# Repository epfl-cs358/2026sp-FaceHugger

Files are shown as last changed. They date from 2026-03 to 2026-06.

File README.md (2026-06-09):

# FaceHugger: An Open-Source Quadruped Robot that Walks, Dances, and Flips

main-robot-stance

In this repo you will find the CAD, firmware, app, simulation, and animation tooling for the FaceHugger quadruped.
This robot was designed and built from scratch by a team of 6 students at EPFL in the [Making Intelligent Things course (CS-358)](https://edu.epfl.ch/coursebook/en/making-intelligent-things-b-CS-358-B) during the Spring 2026 semester.

Find out how to build it and how it works in the _[FaceHugger Wiki](https://epfl-cs358.github.io/2026sp-FaceHugger/)_.

## See it in action

https://github.com/user-attachments/assets/f48a0bcb-4729-4eee-8e89-9a81a8c70e2d

*General moves: walk and wave clips*

https://github.com/user-attachments/assets/28df8788-2bca-48f2-9b82-b47c927adb80

*Dancing clip*

https://github.com/user-attachments/assets/d9c9cdf4-f84c-4cda-ada7-795cacb76790

*Auto-flip: the robot detects when it's upside-down and mirrors its pose*

## Documentation

Project docs are a MkDocs Material wiki under [`wiki/`](wiki/).

- **Live site:** _[FaceHugger Wiki](https://epfl-cs358.github.io/2026sp-FaceHugger/)_
- **How to contribute / fill it out:** see [`wiki/README.md`](wiki/README.md) - structure, local preview,
  adding images/video/3D models/notebooks, and the per-member assignments.

## Repo layout

- `cad/` - Fusion 360 design files and export add-ins
- `code/simulation/` - URDF generator + PyBullet sim ([README](code/simulation/README.md))
- `code/firmware/` - ESP32 firmware (PlatformIO)
- `code/remote-control-app/` - Expo / React Native control app
- `animation/` - Blender rig and animation tooling
- `wiki/` - project documentation (published to GitHub Pages)

## Getting started

```bash
# Simulation
cd code/simulation && conda env create -f environment.yml && conda activate facehugger
python code/facehugger.py sim

# Wiki (local preview)
python -m venv .venv-docs && source .venv-docs/bin/activate && pip install -r requirements-docs.txt
mkdocs serve

# Remote-control app
cd code/remote-control-app/MyApp && npm install && npx expo start --web

# Firmware
cd code/firmware && pio run -t upload
```

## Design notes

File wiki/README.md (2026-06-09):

# Working on the FaceHugger wiki

This folder is the source of the project wiki (a [MkDocs Material](https://squidfunk.github.io/mkdocs-material/)
site). This page explains how the wiki is built and how to contribute to it. It is **not** published to the
site itself; it's here for editors.

## How the wiki works

- **Source:** every page is a Markdown file under `wiki/`. The config is `mkdocs.yml` at the repo root.
- **Two pillars:** `wiki/guide/` is the build guide (for builders/newcomers); `wiki/reference/` is the
  technical depth. Each is a top tab on the site.
- **Navigation** comes from a `.pages` file in each folder (it sets the section's title and page order).
  There is no hand-maintained nav list. Add a page by creating the `.md` and adding its filename to that
  folder's `.pages`.
- **`_context/` folders** hold the original project docs copied verbatim, as source material for writing the
  real pages. They are excluded from the built site but stay in the repo so you can read them on GitHub.
  **Read the `CONSISTENCY-CHECK` note at the top of each `_context/` file first** - many describe designs
  that changed or were never built. Adapt the content, don't paste it. Don't edit `_context/` files; they get
  deleted once the corresponding page is written.
- **Publishing:** a push to `main` touching `wiki/**` runs `.github/workflows/deploy-docs.yml`, which builds
  with `mkdocs build --strict` and deploys to GitHub Pages. A broken link fails the build.

## Working on this branch

We write the wiki on the **`feat/wiki-setup`** branch. The live site only updates when this is merged to
`main`, so until then, **preview locally**.

```bash
git clone https://github.com/epfl-cs358/2026sp-FaceHugger.git
cd 2026sp-FaceHugger
git checkout feat/wiki-setup

# one-time: docs toolchain in an isolated venv
python -m venv .venv-docs
source .venv-docs/bin/activate
# for Windows : .venv-docs/Scripts/activate
pip install -r requirements-docs.txt

# live preview at http://127.0.0.1:8000 (rebuilds as you save)
source .venv-docs/bin/activate && mkdocs serve
# for Windows : .venv-docs/Scripts/activate ; mkdocs serve
```

Edit your pages, then:

```bash
git add wiki/...
git commit -m "docs(wiki): write <page>"
git push                       # pushes to feat/wiki-setup
```

Pull often (`git pull`) so you stay in sync with teammates on the same branch.

## Writing a page

- Pages are stubs with `!!! todo` markers - replace them with real content.
- Keep code fences language-tagged (` ```cpp `, ` ```python `, ` ```yaml `).
- Use admonitions for callouts: `!!! note`, `!!! warning`, `!!! tip`, `!!! danger`.
- Cross-link other pages with relative links so they survive the build's link check.

## Adding images, GIFs, video, 3D models & notebooks

Any non-Markdown file under `wiki/` is copied to the site as-is. Convention: an `img/` folder next to the
page that uses it; shared assets in `wiki/assets/`. Reference with a path relative to the page.

**Images & GIFs:** a GIF is just an image; it animates on its own. Click-to-zoom is automatic (glightbox).

```markdown
![Assembled robot](img/robot.jpg){ width="500" }

<figure markdown="span">
  ![Leg detail](img/leg.png){ width="300" }
  <figcaption>Knee joint, exploded view</figcaption>
</figure>
```

**Video:** for small clips, put an `.mp4` in `img/` with an HTML5 tag. For large videos, use a YouTube embed instead of
committing big binaries to git.

```html
<video controls width="100%"><source src="img/walk.mp4" type="video/mp4"></video>
```

**3D models (STL viewer):** the `<model-viewer>` web component shows interactive 3D, but it loads `.glb`,
not `.stl`. Convert once with [`assets/models/convert_stl_to_glb.py`](assets/models/convert_stl_to_glb.py),
commit the `.glb`, then on the page:

```html
<script type="module" src="https://unpkg.com/@google/model-viewer/dist/model-viewer.min.js"></script>

<model-viewer src="../assets/models/QuadrupedBody.glb" camera-controls auto-rotate
              style="width:100%;height:400px;background:#1a1a2e;"></model-viewer>
```

No-conversion fallback: an iframe to `viewstl.com` pointed at the STL's raw-GitHub URL.

**Interactive notebooks:** `mkdocs-jupyter` is enabled. Drop a `.ipynb` under `wiki/` and add it to the
folder's `.pages`; it renders with its **saved** outputs. The site has no Python kernel, so `ipywidgets`
sliders aren't live. For the torque analysis: ship the notebook read-only and tell readers to run it locally,
or reimplement the controls as a self-contained Plotly HTML widget embedded in an `<iframe>`.

**Math & diagrams:** LaTeX via MathJax: inline `\( ... \)`, block `\[ ... \]`. Diagrams via Mermaid: a
` ```mermaid ` fenced block. Circuit schematics: export from KiCad as SVG and embed as an image.

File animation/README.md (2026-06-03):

# animation/

Blender tooling for the FaceHugger animation pipeline. Each `.py` file declares
its runtime requirement in a two-line header so the reader doesn't have to
scan imports:

    # === Blender-only ===                        (needs the bpy runtime)
    # === Plain Python — no Blender required ===  (pure helpers / stubs bpy)

`scripts/` holds the Blender-driven scene builders — `visualize_urdf.py`,
`urdf_to_blender_rigged.py`, `visualize_fusion_export.py` — entered through
`code/facehugger.py blender [--rigged]`. The folder also carries the
plain-Python helpers `check_export_consistency.py` and `test_servo_parity.py`
that run directly under pytest or `python`; they live here because they
verify the exporter contract.

`addons/` is the Blender add-on (`fh_clip_panel.py`) and its headless
companion (`export_all_clips.py`). The add-on is installed via
Edit > Preferences > Add-ons or reloaded in place by the panel's
"Reload Add-on" button. It is stand-alone — `facehugger.py` does not invoke it.

`lib/` is the shared library both worlds import from: `urdf_parser.py`
(Blender-only — needs `mathutils`), `servo_math.py` (plain Python — kept
byte-identical to the firmware `translateToServo` math, see the parity test),
and `bpy_stub.py` (plain-Python stub of bpy for import-time tests).

Tests live next to the code they test (`scripts/test_*.py`, `addons/test_*.py`,
`lib/tests/test_*.py`), plus repo-level layout and contract checks under
`tests/`. Run them all with `pytest animation/` — Blender-only tests auto-skip
under plain Python via `pytest.importorskip("bpy")`.

## Key files at this level

- `fh_rigged_latest.blend` — the animation library (rig + all authored clips).
  Built/updated by `facehugger.py blender --rigged`; edited by the clip panel.
- `poses.json` — committed pose library consumed by `fh_clip_panel.py`.
- `convention.json` — servo math + channel table for the exporter and parity test.

Servo ID / channel conventions (URDF link names, firmware `LEG_SERVO_CHANNEL`,
the still-open `servo_id` proposal) are documented in
[`wiki/reference/firmware/servo-conventions.md`](../wiki/reference/firmware/servo-conventions.md).

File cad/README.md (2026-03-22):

# CAD Files
Technical drawings and 3D print parameters.

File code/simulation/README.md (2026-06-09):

# FaceHugger simulation pipeline

End-to-end: from the Fusion 360 design, produce a URDF that's faithful to the
CAD and drive it in PyBullet with the exact firmware code compiled to the host.

## Quick start

```bash
# Regenerate the URDF from CAD export
python code/facehugger.py urdf

# Run the sim (standing pose, GUI)
python code/facehugger.py sim

# Play a clip through the exact firmware SIL
python code/facehugger.py sim --clip "wave"

# Walk gait (firmware SIL)
python code/facehugger.py sim --walk

# Open URDF in Blender (rigged armature for animation)
python code/facehugger.py blender --rigged
```

`facehugger.py` is the single CLI entry point — run it from the repo root.

## Packages

| Package | Role |
|---|---|
| `pybullet_sim/` | PyBullet runtime — kinematics, scene lifecycle, motor control, torque monitoring |
| `firmware_sil/` | Software-in-the-loop bridge — compiles the real firmware C++ to a Python module via pybind11 |
| `urdf_gen/` | URDF generator — reads `generated/fusion_export.json` + `facehugger_config.yaml` → `facehugger.urdf` |
| `animation_tools/` | Firmware-faithful clip math (servo convention, clip loader, export parity) |
| `tests/` | Test suite (173 tests) |

## Documentation

Everything else — full CLI reference, config details, the blender pipeline,
controlling the simulation, torque analysis, and limitations — lives in the wiki:

→ **[Simulation documentation](https://epfl-cs358.github.io/2026sp-FaceHugger/reference/simulation/)**

## Prerequisites

```bash
cd code/simulation
conda env create -f environment.yml   # first time only (macOS: conda, Linux: pip works too)
conda activate facehugger             # every session
```

Also needed:
- Fusion 360 with the ExportBodiesToURDF add-in (`cad/scripts/ExportBodiesToURDF/`)
- For the SIL: CMake ≥ 3.15 + C++17 compiler + pybind11 (auto-builds on first use)

Other project envs (wiki, app, firmware) — see the [main README](../../README.md).

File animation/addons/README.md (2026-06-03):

# animation/addons — Blender add-ons

| File | Kind | What it's for |
|---|---|---|
| `fh_clip_panel.py` | UI add-on (sidebar N-panel) | Clips (5-Action bundles), a position-based Pose Library, selection sets, export to `exported_gaits/`, activity heatmap — via the layered Action API. |
| `test_servo_parity.py` | CI test (plain Python) | Verifies `_frame_to_servo` math and channel table against the firmware `tickGait` switch. |

## fh_clip_panel.py — clip + pose tooling add-on

A Blender add-on (not a CLI script) that adds a **"FaceHugger"** tab to
the 3D viewport sidebar (press `N`). The single old "FH Clips" panel is
now a parent panel with five collapsible sub-panels.

Two core data models, kept deliberately separate:

- **Clips** — named groups of 5 Actions on the rig's control objects:
  ```
  <clip_name>__body_ctrl
  <clip_name>__foot_target_{fl,fr,bl,br}
  ```
  Applied via the Blender 4.4+ **layered Action API** (`obj.animation_data.action`
  + `.action_slot`). No NLA, no drivers — direct per-object assignment.
- **Poses** — a position-based library in committed `animation/poses.json`
  (single-source-of-truth file, same pattern as `convention.json`). A
  *pose* is a snapshot of the 5 controls' **local** transforms
  (`body_ctrl` loc+rot, the 4 `foot_target_*` loc only — the IK reads
  only foot-target position). Poses are **clip-independent**: applying a
  pose sets transforms *only* — no keyframes, no Action/clip side
  effects. Local transforms are stored so a pose round-trips with
  keyframes ("Key into Clip").

### Loading

| Method | When to use |
|---|---|
| `Edit > Preferences > Add-ons > Install...` → pick this file → enable "FH Clip Panel" | Persists across sessions. Use for actual animation work. |
| Open in Text Editor → press `Alt+P` (Run Script) | Dev iteration. The script unregisters before re-registering, so you can edit and re-run without restarting Blender. |

### Panel structure

- **(parent) FaceHugger** — always-visible status: active-clip header,
  and the *not-keyed notice*. Applying a pose is a live viewport change
  with nothing committed; the parent shows a yellow `Pose '<name>' applied
  — not keyed` plus a one-click `Key into '<clip>' @ frame N` button that
  inserts the 5 keyframes into the active clip's own Actions at the
  recorded frame.
- **Poses** — one row per library pose: Apply · Rename · Delete.
- **Clips** — one button per clip; the ⟳ icon overwrites that clip with
  the currently-bound animation (confirm dialog). New Clip · Duplicate ·
  Rename · Save Current → New Clip.
- **Selection** — `All · Body · Legs · Front · Back · FL · FR · BL · BR`.
  Pure viewport selection — touches no data.
- **Export** — CSV / `.h` / `.js` toggles; Export Active Clip; Clips to
  export checklist + Export Selected Clips → `animation/exported_gaits/<clip>/`.
- **Display** (collapsed) — Activity Heatmap: colours per-joint servo meshes
  by per-frame angle delta (green→orange→red).

### Operator IDs

```python
bpy.ops.fh.apply_clip(clip_name="stand up")
bpy.ops.fh.new_clip()
bpy.ops.fh.save_as_clip()
bpy.ops.fh.duplicate_clip()
bpy.ops.fh.overwrite_clip(clip_name="walk")
bpy.ops.fh.rename_clip()
bpy.ops.fh.export_clip()
bpy.ops.fh.export_selected()

bpy.ops.fh.pose_save()
bpy.ops.fh.pose_apply(pose_name="flat")
bpy.ops.fh.pose_rename(pose_name="old")
bpy.ops.fh.pose_delete(pose_name="flat")
bpy.ops.fh.key_pose_into_clip()
bpy.ops.fh.set_n_pose()     # console re-seed + apply 'neutral'
bpy.ops.fh.set_rest_pose()  # console re-seed + apply 'flat'
bpy.ops.fh.select_controls(preset="LEGS")
```

### Typical workflow

1. **Block out a stance.** In **Poses**, Apply `flat` / `standing` (or your own).
2. **Pick a clip to work in.** In **Clips**, Apply the clip (or `New Clip`).
3. **Commit the pose.** Click *Key into '<clip>' @ frame N* in the notice.
4. **Edit the clip.** While a clip is active, every keyframe lands directly in its Actions. Ctrl-S the `.blend`.
5. **Export.** Tick CSV / `.h` / `.js`, then Export Active Clip or Export Selected Clips → `animation/exported_gaits/<clip>/`.

### Running an exported `.js` clip in a browser

1. Tick **Browser JS (.js)**, hit *Export Active Clip* → `animation/exported_gaits/<clip>/<clip>.js`.
2. Join the robot's Wi-Fi (`FaceHugger_Net`, `192.168.4.1`). Open a console on a non-HTTPS page (`ws://` is blocked from `https://`).
3. Stop any active gait before playing:
   ```js
   ws.send(JSON.stringify({"T": 5, "g": 0}));  // CMD_GAIT_MODE → GAIT_NONE
   ws.send(JSON.stringify({"T": 2, "s": 0}));  // CMD_STATE → STATE_IDLE
   ```
4. Paste the `.js`. Call `fhStop()` to stop.

See [`doc/animation-pipeline/onboard-clip-player-design.md`](../../doc/animation-pipeline/onboard-clip-player-design.md) for Phase-1 design context.

### Servo math contract

`_frame_to_servo` in the exporter is verified byte-identical to the firmware
`tickGait translateToServo` switch. Run `uv run python animation/addons/test_servo_parity.py`
to assert both the math and the channel table against `origin/main`.

See [`wiki/reference/firmware/servo-conventions.md`](../../wiki/reference/firmware/servo-conventions.md)
for the broader servo ID / channel convention.

### What's next

- **Binary `.fhc` exporter** — a Layer-2 converter to the on-board binary playback format once it lands (see [doc/animation-pipeline/](../../doc/animation-pipeline/)).
- **Torque heatmap** — gravity-hold torque mode for the Display heatmap; scoped in the [Torque heatmap wiki page](../../wiki/reference/simulation/torque-heatmap.md) under "Planned: gravity-hold torque mode".

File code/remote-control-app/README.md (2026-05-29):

# FaceHugger Remote Control App

A React Native (Expo) mobile app for controlling the FaceHugger quadruped robot over Wi-Fi. It communicates with the ESP32 firmware via WebSocket on port 81, following the protocol defined in [`code/API_SPEC.md`](../API_SPEC.md).

---

## How to run

```bash
cd code/remote-control-app/MyApp
npm install
npm run start          # opens Expo dev server
npm run android        # or: npm run ios / npm run web
```

The robot's ESP32 acts as a Wi-Fi access point. Connect your phone to that network, then launch the app. The target IP is hardcoded in `config/config.ts`:

```ts
export const webSocketIP = "192.168.4.1"  // ESP32 AP gateway
```

---

## App layout

The app has a persistent header and three swappable pages selected from a bottom navigation bar.

### Persistent header (always visible)

| Section | What it shows |
|---|---|
| Logo | FaceHugger image |
| Connection status | Green "Connected" / red "Not Connected" pill |
| Telemetry bar | Gait mode, speed (m/min), gyroscope X/Y/Z, error message (if any) |

The telemetry bar is populated from the `T:10` status packets the robot broadcasts every ~500 ms. It is hidden when the socket is disconnected.

---

### Page 1 — Remote Control (game-controller icon)

The main driving interface. Switching to this page sends `STATE_WALK` to the robot's FSM.

**Joystick** — drag to steer. The joystick maps angular sectors to the eight direction commands sent over WebSocket (`T:1`):

| Sector | Direction |
|---|---|
| Up | Forward |
| Up-right / Up-left | Forward-right / Forward-left |
| Right / Left | Strafe right / Strafe left |
| Down-right / Down-left | Backward-right / Backward-left |
| Down | Backward |

Releasing the joystick sends a `STOP` command. The firmware enforces a 2-second timeout: if no movement command arrives while in `STATE_WALK`, the robot reverts to idle on its own.

**Gait mode dropdown** (bottom-right corner) — switches between:

| Mode | Description |
|---|---|
| TROT | Diagonal pairs move together — faster, natural walking gait |
| CRAB | Legs move independently for lateral / omnidirectional travel |

Selecting a gait sends a `T:5` packet immediately and is remembered across reconnects.

---

### Page 2 — Actions (fire icon)

One-shot commands that put the robot into `STATE_ACTION`. Three buttons are available:

| Button | What it does |
|---|---|
| Invert robot | Triggers the wall-flip / inversion maneuver (`T:6, a:0`). A confirmation prompt appears before the command is sent. |
| Rest pose (all servos 90°) | Sends 12 `T:4` calibration packets — one per joint — driving every servo to 90°. Useful as a neutral reset before calibration. |
| Neutral stance | Sends 12 `T:4` packets with the firmware's default standing angles (mirroring `returnToDefaultAngles()` in the firmware). Brings the robot to its nominal standing pose. |

Neutral stance angles (hip / thigh / knee, degrees):

| Leg | Hip | Thigh | Knee |
|---|---|---|---|
| Front right (0) | 90 | 150 | 53 |
| Front left (1) | 75 | 30 | 130 |
| Rear right (2) | 90 | 40 | 130 |
| Rear left (3) | 90 | 150 | 50 |

Keep `NEUTRAL_STANCE_ANGLES` in `api/api-messages.tsx` in sync with the firmware `*_DEFAULT_ANGLE` constants in `config.h` if those ever change.

---

### Page 3 — Individual Control (engine icon)

Direct per-servo angle control, primarily for calibration. Switching to this page sends `STATE_IDLE` to the robot's FSM (gait engine off, servos hold position).

**Workflow:**
1. Pick a leg: Front Right, Front Left, Back Right, Back Left.
2. Pick a servo: Hip, Thigh, Knee.
3. Type an angle (0–180°) and tap **Send angle**.

Each send fires a single `T:4` calibration packet. The input field remembers the last-sent angle for each (leg, servo) pair within the session.

---

## State management

Global state is managed with **Zustand** (`store/robotStore.ts`). The store holds:

- `fsmState` — current FSM state reported by the robot
- `chosenFsmState` — the state the app has requested (sent on tab switch)
- `gaitMode` / `chosenGaitMode` — same pattern for gait
- `tofDistances` — ToF sensor readings `[FL, FR, RL, RR, Center]`
- `speed`, `gyroscope` — from the AMU array in `T:10`
- `movementProgress` — gait cycle completion (0.0–1.0)
- `errorMessage` — firmware error string, or `null`

On reconnect, the app immediately re-sends the last chosen FSM state and gait mode so the robot snaps back to the correct configuration without any manual intervention.

---

## WebSocket protocol summary

Full spec: [`code/API_SPEC.md`](../API_SPEC.md). Quick reference:

| T | Direction | Purpose |
|---|---|---|
| 1 | App → Robot | Movement direction command |
| 2 | App → Robot | FSM state transition |
| 3 | App → Robot | Body pose / static IK (pitch, roll, height) |
| 4 | App → Robot | Direct servo angle (calibration) |
| 5 | App → Robot | Gait mode change |
| 6 | App → Robot | Trigger action (e.g. invert) |
| 10 | Robot → App | System status telemetry |

---

## Project structure

```
MyApp/
├── App.tsx                  # root: sets up Pager + WebSocket connection
├── config/config.ts         # robot IP, debug flag
├── api/
│   ├── api-types.tsx        # enums + TypeScript types for all packets
│   └── api-messages.tsx     # pre-built packet objects + helper constructors
├── services/socket.ts       # raw WebSocket wrapper (connect / send / onMessage)
├── hooks/
│   ├── useRobotConnection.ts  # subscribes to T:10, re-syncs state on reconnect
│   └── useSocketStatus.ts     # boolean reactive connection state
├── store/robotStore.ts      # Zustand global state
├── screens/
│   ├── GaitControl.tsx      # Remote Control page
│   ├── Actions.tsx          # Actions page
│   └── LegControl.tsx       # Individual Control page
└── components/
    ├── pager/               # bottom-nav tab container + persistent header
    ├── joystick/            # gesture-based joystick
    ├── connectionStatusComponent/
    ├── robotStatus/         # telemetry display bar
    ├── dropdown/            # gait mode selector
    ├── IndividualSelectionButton/
    └── textInput/ / text/   # shared form primitives
```

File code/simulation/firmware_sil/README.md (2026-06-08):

# firmware_sil — run the exact firmware code in the sim (SIL)

Software-in-the-loop: the **actual flashed firmware C++** (`SpinalCord`, compiled
unchanged from `code/firmware/src/`) runs on the host and computes the 12 servo
angles; `sil_bridge.py` turns those into URDF joint targets and drives PyBullet.
No Python re-port is in this path, so a clip that looks right here issues the same
servo commands on the real robot.

## How it works

```
clips_all.h (firmware copy) ──► fh_sim (compiled SpinalCord) ──► 12 servo degrees
                                       │  tick(t_ms) advances an injected clock
                                       ▼
                          sil_bridge.servo_angles_to_joint_targets
                                       ▼
                          pybullet.setJointMotorControl2  (POSITION_CONTROL)
```

The firmware sources are compiled against host shims in `hal/` (zero firmware
changes):

| `hal/` file | shadows | role |
|---|---|---|
| `Arduino.h` | `<Arduino.h>` | `millis()` reads an **injected** sim clock (`fh_sim::clock_ms`, set per tick); `map`/`constrain` real; `Serial` no-op; `String = std::string`. |
| `Wire.h` | `<Wire.h>` | empty stub. |
| `Adafruit_PWMServoDriver.h` | the PCA9685 driver | recording mock; `setPWM` stores the pulse per channel. |
| `network_stubs.h` | WiFi/WebSockets | placeholder; unused in Step 1 (`network.cpp` isn't compiled). |

> The SIL plan (D1) names ByteNana/ArduinoMock for a fuller Arduino surface. The
> compiled control files use only `millis`/`map`/`constrain`/`Serial`/`String`, so
> this hand-rolled shim is the smaller, network-free, deterministic equivalent.
> Swap in ArduinoMock via `FetchContent` if a future file needs more of Arduino.

## Build

Requires a C++17 compiler, CMake ≥ 3.15, and `pybind11` (in the conda env:
`conda install -n facehugger -c conda-forge pybind11`).

```bash
cd code/simulation/firmware_sil
cmake -S . -B build -DPython_EXECUTABLE=$(which python)
cmake --build build
```

Produces `build/fh_sim.<ext>.so`. It is **not committed** (rebuilt locally / in
CI). Contributors without a C++ toolchain skip this and use the Python re-port
(`animation_tools/`); `tests/test_sil_poc.py` skips automatically when `fh_sim` is absent.

### Auto-rebuild (no stale firmware)

The firmware driver never runs a stale `.so`: `sil_bridge.load_fh_sim()` compares
the built module's mtime against every source under `code/firmware/src/`, `hal/`,
`bindings.cpp`, and `CMakeLists.txt`, and **recompiles before importing** if any
is newer (or the `.so` is missing). So editing firmware and re-running
`code/facehugger.py sim --clip ...` always reflects the change.

- Skip the auto-rebuild (warn loudly instead): set `FH_SIL_NO_BUILD=1`.
- Optional pre-run freshness gate (no GitHub CI is set up for this):
  ```bash
  python -m firmware_sil.sil_bridge --check   # exit 1 if stale (no build)
  python -m firmware_sil.sil_bridge           # rebuild if stale, then report
  ```

## Use it

```bash
python code/facehugger.py sim --clip "wave" --headless            # DEFAULT: exact firmware (auto-built)
python code/facehugger.py sim --clip "wave" --headless --python   # force the Python re-port (no toolchain)
```
Clip playback **defaults to the exact firmware**; `--python` forces the re-port
(`animation_tools/`). Only `--clip` uses this driver — stand/`--walk`/`--trot` are
unaffected, so a toolchain-less machine can still run those.

## Verify (run from code/simulation/, not this dir)

```bash
cd code/simulation
conda run -n facehugger python -m pytest tests/ -v
```

- `tests/test_sil_poc.py` — the firmware plays a clip with all angles in `[0,180]`; SIL
  matches the Python re-port at frame 0 within the firmware's whole-degree
  truncation (≤ 1°); the bridge drives PyBullet headless; the default clip path
  (no flag) runs end-to-end through the firmware.
- `tests/test_sil_clip_suite.py` — replays every clip through the firmware and compares
  to its committed reference trace (`reference_clips/*.json`). Clips listed under
  `reference_clips:` in `facehugger_config.yaml` must match exactly; all other clips
  only warn on mismatch. Regenerate: `python code/facehugger.py update-reference-clips`.

## Golden traces

`golden/<clip>.json` is the recorded servo-angle trace (10 Hz, whole degrees) the
firmware produces for each clip — the exporter/firmware regression baseline.
Regenerate **only** for intentional changes, then review the diff:

```bash
cd code/simulation && conda run -n facehugger python -m firmware_sil.gen_golden
```

## WebSocket robot API (drive from the app / a browser panel)

`ws_sim.py` serves the API_SPEC `T:` protocol and drives a PyBullet robot with the
firmware. **The command routing is the compiled firmware**: each message is handed
to the firmware's own `network.cpp::handleParsedMessage` (compiled into `fh_sim`
alongside ArduinoJson + `clip_list_serializer`), so any change to the firmware's
API handling reflects automatically — no Python mirror to drift. Only the
WebSocket transport and the periodic telemetry are Python.

```bash
python code/facehugger.py sim --serve            # ws://localhost:8081  (or, from code/simulation: python -m firmware_sil.ws_sim)
```

Then open the control panel (no build/deps). Easiest: run `python code/facehugger.py
sim --panel` and open the printed `http://localhost:8082/panel`. Or open the file
directly at `code/remote-control-app/control-panel/robot_control_panel.html` and set
the target to `ws://localhost:8081` and Connect. One button per API command (clip
discovery T:8, play T:7, state T:2, move T:1, gait T:5, invert T:6, calibrate T:4);
it shows the exact JSON sent and logs replies. The **same panel drives the real
robot** — point it at `ws://<robot-ip>:81`. The unmodified app can connect too.

Port note: the real robot uses **81** (privileged on macOS/Linux), so the sim
defaults to **8081**. `--port 81` works with sudo for true parity.

### Drive the real Expo app against the sim

The full mobile app (`code/remote-control-app/MyApp`) can drive the sim exactly as
it drives the robot. One command brings up the sim, the WebSocket API, and the app:

```bash
python code/facehugger.py sim --app --host 0.0.0.0   # sim + WS API on :8081 + Expo web app
```

Then in the app's **Settings** screen, tap the **Simulator** preset (or enter the
dev machine's LAN IP and port `8081`). Tap **Robot** to target hardware again. (To
run only the server, use `sim --serve --host 0.0.0.0` and start the app yourself.)
The app and the Mac must be on the same network.

## Sim telemetry (SSE, local debug only)

Alongside the WS API, `serve` streams a per-joint telemetry frame over
**Server-Sent Events on :8082** (`http://localhost:8082/telemetry`) at ~20 Hz. This
is sim-only — the real robot doesn't serve it — and it's best-effort: if
`sse-starlette`/`uvicorn` aren't installed the WS API still runs, telemetry just
disabled. Each frame is `{t, joints:[12 × {…}]}` in order FL, FR, BL, BR ×
shoulder/hip/knee, where every joint carries **both** spaces:

- `commanded_servo_deg` — the firmware's 0–180 output (what the real servos receive, 90 = neutral),
- `commanded_joint_deg` — that same command in URDF-joint degrees (0 = neutral), comparable to actual,
- `actual_joint_deg` — the measured PyBullet joint angle,
- `delta_deg` — `commanded_joint − actual` (a true tracking error),
- `torque_nm` / `current_a` — from PyBullet + `sim_monitor`,
- `pre_clamp_deg` — the firmware's pre-clamp `[OOR]` request for that servo this tick, else null.

The control panel (`code/remote-control-app/control-panel/robot_control_panel.html`)
renders this in its "Sim telemetry" table (Δ red
when |Δ|>5°, τ coloured by `sim_monitor.band()` — green = safe continuous
(<~0.98 N·m), amber = burst (under stall), red = saturated (≥2.94 N·m stall) — a
Clamp column from `pre_clamp_deg`, and a stale banner when frames stop). With
`--gui`, the PyBullet links are torque-tinted the same way every 12th step. The `pre_clamp_deg` value comes from a real firmware
feature: `Leg::setJointAngles` / `Servo::setServoAngle` print `[OOR] servo <ch>
requested <deg>` before clamping to [0,180] (visible on the bench serial monitor),
which the SIL's Serial mock captures.

```bash
python code/facehugger.py sim --serve --gui            # ws://localhost:8081 + SSE http://localhost:8082/telemetry
```

## Status

Steps 1–3 of `docs/.work/pybullet-sim/EXACT-FIRMWARE-SIL-PLAN.md` done: SIL clip
playback, the golden-trace suite, the `--python` fallback, and the firmware-backed
WebSocket API + control panel. Plus: firmware `[OOR]` pre-clamp warnings (captured by
the SIL) and the SSE sim-telemetry stream (:8082) + panel table.

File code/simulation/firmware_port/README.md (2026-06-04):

# pybullet_interpreter

Python module that mirrors the FaceHugger firmware clip pipeline, letting you
validate animation clips in PyBullet before flashing.

## Purpose

The firmware plays clips via `tickClip()` in `spinal_cord.cpp`, which calls
`translateToServo()` and `clampClipServos()` from `motion_math.cpp`. This module
ports that exact math to Python so the same clip data can be driven through a
PyBullet simulation and inspected visually.

EMA smoothing (`CLIP_EMA_ALPHA=0.75` in firmware) is intentionally **not**
reproduced here — the goal is validating clip geometry, not smoothing artifacts.

## Files

| File | Role |
|---|---|
| `servo_convention.py` | Firmware math ported to Python: `translate_to_servo`, `clamp_clip_servos`, `servo_to_radians`, `NEUTRAL` constants |
| `clip_loader.py` | Parses `animation/exported_clips/clips_all.h` into `ClipData` / `ClipFrame` dataclasses |
| `clip_player.py` | Interpolates clip frames and drives PyBullet joints; `ClipPlayer.play_blocking()` runs in real time |
| `gait_interpreter.py` | Stub — not yet implemented |

## Usage

Play a clip from the command line:

```bash
# from code/simulation/
python facehugger.py sim --clip "tiny wiggle"
python facehugger.py sim --clip "tiny wiggle" --headless   # CI / no window
```

Or drive it from Python:

```python
from pybullet_interpreter.clip_loader import DEFAULT_CLIPS_H, get_clip_by_name, load_clips_all_h
from pybullet_interpreter.clip_player import ClipPlayer

clips = load_clips_all_h(DEFAULT_CLIPS_H)
clip  = get_clip_by_name(clips, "tiny wiggle")

player = ClipPlayer(robot_id, joint_map, clip)
player.play_blocking(gui=True)
```

`robot_id` and `joint_map` come from the existing PyBullet setup in `scene.py`
(`_connect_and_setup` + `build_joint_map`).

## Pipeline

```
clips_all.h  →  load_clips_all_h()  →  ClipData.frames (a[12], ms)
                                              │
                                    _interpolate_frame(elapsed_ms)
                                              │
                                    frame_to_joint_targets(a)
                                      ├── translate_to_servo(leg_id, sh, th, kn)
                                      ├── clamp_clip_servos(servo)
                                      └── servo_to_radians(deg)
                                              │
                                    pybullet.setJointMotorControl2(...)
```

## Tests

Pure-math tests (no PyBullet required):

```bash
# from code/simulation/
uv run --with pytest python -m pytest pybullet_interpreter/tests/ -v
```

53 tests across `servo_convention`, `clip_loader`, and `clip_player`.

## Firmware correspondence

| Python | Firmware |
|---|---|
| `translate_to_servo()` | `translateToServo()` — `motion_math.cpp:32` |
| `clamp_clip_servos()` | `clampClipServos()` — `motion_math.cpp:10` |
| `_interpolate_frame()` | `clipPoseAt()` — `motion_math.cpp:62` |
| `ClipPlayer.step()` | inner loop of `tickClip()` — `spinal_cord.cpp:427` |
| `NEUTRAL[]` | `NEUTRAL[LEG_COUNT]` — `neutral_pose.h:13` |

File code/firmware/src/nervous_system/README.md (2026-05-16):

# 🦵 Nervous System Abstraction (Absolute Geometry) v2.0

This directory serves as the "Peripheral Nervous System" of the FaceHugger quadruped. It bridges the gap between pure mathematical motion planning and the quirky physical reality of hobby servo motors. 

We have transitioned from the old "80/20 Hardcoded Offset" approach to a **Universal Geometric Coordinate System**, achieving complete separation of concerns between the robot's mathematical intent and its hardware execution.

## 🏗️ Architecture & File Structure

Based on our recent kinematic discoveries, the nervous system is split into distinct functional layers to isolate hardware quirks from pure math:

### 1. The Gait Engine (`spinal_cord.cpp` / `spinal_cord.h`)
**Role:** The Choreographer.
* **Primary Function:** Orchestrates the Walk Cycle (State Machine).
* **Smooth Movement:** Utilizes Linear Interpolation (LERP) to generate micro-steps between keyframes, completely eliminating robotic "jerks" and preserving momentum.
* **Logic:** Handles high-level timing for the Static Creep Gait, deciding which legs lift, reach, plant, or sweep. 

### 2. The Math Brain (`kinematics.cpp` / `kinematics.h` & `movements.h`)
**Role:** The Universal Blueprint.
* **Logic:** All movement is planned in absolute mathematical degrees, entirely ignorant of how the motors are physically mounted.
* **Reference:** `0°` is always perfectly horizontal. Negative angles point down/backward, positive angles point up/forward.
* **Keyframes:** `movements.h` stores the different gait parameters and types, as well as the leg IDs

### 3. The Hardware Translator (`leg.cpp` / `leg.h`)
**Role:** The Symmetry Compensator.
* **Primary Function:** `setPose()` / Translating Math to Physical Angles.
* **Logic (Diagonal Symmetry):** Compensates for the physical mirroring of the robot's motors:
  * **Front-Right (FR) & Back-Left (BL):** Share one mechanical inversion (`90 - Math`).
  * **Front-Left (FL) & Back-Right (BR):** Share the opposite mechanical inversion (`90 + Math`).
* **Safety:** Implements hard `constrain(0, 180)` limits to prevent software glitches from commanding the servos to rip the plastic chassis apart.

### 4. The Muscle (`servo.cpp` / `servo.h`)
**Role:** The Hardware Interface.
* **Logic:** The lowest-level abstraction. Maps the translated 0-180° angles to PWM pulse widths for the PCA9685 via I2C.

---

## 🔗 Functional Mapping

| Phase | File | Role |
| :--- | :--- | :--- |
| **Communication** | `network.cpp` *(external)* | **Interpreter:** Receives JSON commands via WebSocket. |
| **Gait Orchestration** | `spinal_cord.cpp` | **Planner:** Calculates LERP micro-steps and manages the state machine. |
| **Pure Geometry** | `kinematics.cpp` / `movements.h` | **Math Brain:** Determines absolute target angles (e.g., Thigh -60°). |
| **Hardware Mapping** | `leg.cpp` | **Translator:** Translates math to diagonal physical pairs (0-180°). |
| **Execution** | `servo.cpp` | **Muscle:** Calls I2C commands to write specific PWM values to the 12 channels. |

---

## 📐 Calibration Philosophy (The "Superman" Pose)

We abandoned continuous software offset hunting in favor of strict physical calibration. To ensure the hardware perfectly matches the software's geometric assumptions:

1. **Software Zero:** Send exactly `90` to all 12 servo channels.
2. **Physical Zero:** While the motors hold at `90`, attach the 3D-printed leg pieces so they point **perfectly straight out horizontally** (The "Superman" or "T-Pose").
3. **Result:** A command of `90` is now mechanically locked to Mathematical `0°`. All Inverse Kinematics and geometric math work flawlessly out of the box.

---

## 📐 Coordinate System

Each leg operates in its own absolute geometric space:
* **Global Shoulders:** Shoulders are mapped to a global compass: FR (+45°), FL (+135°), BR (-45°), BL (-135°).
* **Horizontal Zero:** The Thigh and Knee treat `0°` as parallel to the floor.
* **Negative Angles:** Point towards the floor (Thigh) or tuck backward (Knee).

---

## 🛠️ Milestone: Hardware Integration (v1)

**Current Branch Goal:** Complete the **Leg Layer** and **Execution** phase.
* **Success Criteria:** A `CMD_CALIBRATE` JSON packet successfully targets a specific PCA9685 pin and moves a joint to a precise pulse width.
* **Focus:** Stabilizing the I2C communication between the ESP32 and the PCA9685 driver.

## 🛠️ Milestone: Autonomous Static Walk (v2)

**Current Status:** Successfully achieved the first continuous, autonomous static walk cycle using smoothly interpolated geometric arrays via WebSockets!

**Next Steps / Current Focus:**
* **Traction:** Add rubber/silicone to the 3D-printed feet to prevent slippage and loss of forward momentum.
* **Center of Mass (CoM) Sway:** Implement dynamic body-shifting in `spinal_cord.cpp` to properly lean the robot's weight into the support polygon *before* lifting a rear leg, preventing backwards tilting and instability.

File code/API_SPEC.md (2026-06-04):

# FaceHugger API Specification v1.1

This document defines the JSON-based communication protocol between the **Web Dashboard** and the **ESP32 Firmware**.

## 📡 Transport Layer
- **Protocol:** WebSocket (Bi-directional)
- **Port:** 81
- **Format:** Minified JSON
---

## Direction vector type
The direction vector of the robot
- **FW (id 0):** Forward vector (0.0, 1.0)
- **BW (id 1):** Backward vector (0.0, -1.0)
- **FR (id 2):** Front right vector (1.0, 1.0)
- **FL (id 3):** Front left vector (-1.0, 1.0)
- **BR (id 4):** Backward right (1.0, -1.0)
- **BL (id 5):** Backward left (-1.0, -1.0)
- **STOP (id 6):** Stop, user finished walking so we send a message to stop and finish the action (0.0, 0.0)

## Gait Mode Type 
The gait mode the robot is currently in
- **TROT (id 0):** Trot gait mode
- **CRAB (id 1):** Crab gait mode
- **CRAWL (id 2):** Crawl gait mode

## 📥 Dashboard -> Robot (Commands)

### 1. Manual Movement (`T: 1`)
Real-time body vector and gait control.
| Key | Type  | Description | Range |
| :-- | :---- | :--- | :--- |
| 'd' | int | FW, BW, FR, FL, BL, BR, R, L | 0,1,2... |

**Example:** `{"T": 1, "d": 0}`

---

### 2. Finite State Machine (FSM) Transition (`T: 2`)
Requests a change in high-level behavior.
| Value (`s`) | State | Description |
| :--- | :--- | :--- |
| **0** | **IDLE** | Static hold / Active balancing. |
| **1** | **WALK** | Gait engine active. |
| **2** | **ACTION** | Triggers Wall-Flip / Specialized maneuvers. |
| **3** | **FAILSAFE**| Emergency software interrupt. |
| **4** | **REST** | Flat / all-servos-90 calibration pose; clears the invert flag. Safe to power off. |
| **5** | **STAND** | Standing / neutral pose (per-leg `NEUTRAL[]`); the gait launch reference. |

Out-of-range `s` is ignored. State 4 (REST) is the pose to assume when physically
calibrating the robot: all servos go to mid-travel and you mount the links to match.

**Optional `dur_ms`** (uint, ms): on the two pose states REST (4) and STAND (5),
specifies an ease window for the transition into the pose. The firmware glides
each joint to the target over `dur_ms` ms using the same timed-move infrastructure
as the clip-return ease (`setJointAnglesTimed`). Default / absent / `0` means
snap (the original instant pose write). Clamped on the firmware to
`[0, POSE_EASE_MS_MAX]` (= 5000 ms) so a bad value can't park the robot in a
multi-minute ease. Ignored on non-pose states (IDLE / WALK / ACTION / FAILSAFE).

**Examples:**
- `{"T": 2, "s": 5}` — snap to standing neutral (existing behaviour).
- `{"T": 2, "s": 5, "dur_ms": 1000}` — ease into standing neutral over 1 s
  (the default the app sends from the REST / NEUTRAL pose buttons).

---

### 3. Body Pose / Static IK (`T: 3`)
Adjusts the orientation of the chassis while the feet stay planted. We are in `STATE_ACTION`.
Orientation of the chassis with feet planted.
| Key | Type  | Description | Unit |
| :-- | :---- | :--- | :--- |
| `h` | int | Chassis Height | mm |
| `p` | float | Pitch (Tilt forward/back) | degrees |
| `r` | float | Roll (Tilt side-to-side)  | degrees |

---

### 4. Servo Calibration (`T: 4`)
Direct angle control over a specific PCA9685 channel — a **raw servo write**
that bypasses `translateToServo` and CALIB. Reserved for hardware calibration
sessions (the per-joint zero-point sweep, `LegControl` screen). **Do not use
for clip streaming** — that path is T:12 (`CMD_STREAM_FRAME`), which sends
math-space joint angles and lets the firmware apply translateToServo + CALIB
on receipt. Coupling clip authoring to firmware CALIB via T:4 was retired in
Phase 2 of the CALIB-decoupling plan.

| Key  | Type | Description | Range |
| :--- | :--- | :--- | :--- |
| `id` | int  | leg id | 0 - 3 |
| `servo_id`| int | servo id (0: hip, 1: thigh, 2: knee) | 0 - 2|
| `a`  | int  | Angle | 0-180 |

**Example:** `{"T": 4, "id": 2, "servo_id": 2,"a": 90}` *(Move knee of leg id 2 (bottom right) to 90 degrees)*

### 5. Gait integration ('T: 5')
Gait mode change
| Key | Type | Description | Range |
| :-- | :---- | :--- | :--- |
| 'g' | int  | Gait mode ID | 0,1,2...|
**Example:** '{"T": 5, "g": 1}' *(This is needed in order to avoid sending the gait each time with the T: 1 packets as well as have a separation of concern as to what the robot should do when changing gait)*

### 6. Set Auto-Invert (`T: 6`) — `CMD_SET_AUTO_INVERT`

Sets whether the firmware is allowed to drive its `isInverted` flag off the
MPU6050 upside-down latch (`tickImu`). When enabled, `main.cpp` forwards the
hysteresed latch to `spinalCord.setInverted(...)` on every change. When
disabled, the IMU loop is ignored and `isInverted` is frozen at its current
value — useful, for example, while bench-calibrating the robot upside-down
without making the firmware mirror gaits.

Replaces the older `CMD_ACTION_SELECTION` carrier (manual "invert robot"
button, removed from the app once IMU auto-flip landed).

| Key | Type | Description |
| :--- | :--- | :--- |
| `enabled` | bool | `true` = allow IMU to flip `isInverted`; `false` = freeze |

Firmware default is **ON** (`true`). Missing or non-bool `enabled` key → silent
no-op (lets a probe packet `{T:6}` be sent without changing state). The current
value is mirrored back on every `T:10` broadcast as `auto_invert_enabled` so
the UI can re-sync on reconnect.

**Example:** `{"T": 6, "enabled": false}` *(freeze invert; the IMU will keep
running and report `upside_down` in telemetry, but the FSM won't react)*

### 9. Set Invert Flag (`T: 9`)
Set the robot's invert flag without triggering any servo movement or pose change.
The mirror is applied transparently on the next motion tick (gait, clip, or stand)
via `applyServos`. Use this when you want to arm or disarm invert mid-animation
without interrupting clip playback.

| Key | Type | Description |
| :--- | :--- | :--- |
| `inverted` | bool | `true` = inverted (upside-down), `false` = upright |

Missing or non-bool `inverted` key → silent no-op with Serial warning.

**Example:** `{"T": 9, "inverted": true}` *(arm invert; next motion tick applies the mirror)*

---

### 11. Set Clip Smoothing (`T: 11`)
Set the clip-playback smoothing factor (per-channel EMA alpha) at runtime — no
reflash. Lower = snappy, follows the baked frames exactly; higher = smoother but
laggier. The firmware clamps to a safe range so playback can never stall. Affects
clip playback only (not gaits or calibration).

| Key | Type  | Description | Range |
| :-- | :---- | :--- | :---- |
| `a` | float | EMA alpha (smoothing amount) | 0.0–0.95 (clamped); boot default 0.75 |

**Example:** `{"T": 11, "a": 0.5}` *(less smoothing — snappier clips)*

---

### 12. Stream Clip Frame (`T: 12`) — `CMD_STREAM_FRAME`

Send one animation frame in **math-space** (mechanical joint angles, independent
of hardware calibration). The firmware converts to servo angles at runtime via
`translateToServo` and `applyInvert`, so exported clip files never need to be
regenerated after recalibration.

| Key  | Type | Description |
| :--- | :--- | :--- |
| `fr` | float[3] | Front-right leg `[shoulder, thigh, knee]` in math-space degrees |
| `fl` | float[3] | Front-left leg `[shoulder, thigh, knee]` |
| `br` | float[3] | Back-right leg `[shoulder, thigh, knee]` |
| `bl` | float[3] | Back-left leg `[shoulder, thigh, knee]` |

**Math-space convention:** Shoulder 0° = legs pointing straight forward. Positive
shoulder = CCW rotation (uniform across all legs). Thigh/knee follow the URDF
joint convention defined in the sim (`shoulder_rest`, `thigh_rest`, `knee_rest`).

**Dirty-flag optimization:** Joints where the computed servo angle has changed
by less than `SERVO_DEADBAND_DEG` (0.5°) since the last frame are skipped;
no PWM write is issued. This filters floating-point noise and reduces bus
traffic in near-static frames.

**Invert-aware:** If the robot is currently inverted (`isInverted = true`),
`applyInvert` is applied to the servo triple before writing — the same mirror
used by gaits and the on-board clip player.

**Example:** `{"T": 12, "fr": [0.0, -10.5, 20.3], "fl": [0.0, -10.5, 20.3], "br": [0.0, -10.5, 20.3], "bl": [0.0, -10.5, 20.3]}`

Missing or wrongly-typed leg arrays are silently rejected (the whole frame is
dropped). Used by browser-streamed clip playback (exported `.js` files) **and
by the mobile-app clip streamer** (`code/remote-control-app/MyApp/services/
clipStreamer.ts`); both read math-space frames from the same exporter pipeline
(`fh_clip_panel.py:to_js` / `to_clips_extra_json`, bundle tagged
`wire: "T12"`).

---

### 7. Play Clip ('T: 7')
Play a bundled animation clip by id. By default the robot plays the clip once on
its baked timeline, then auto-returns to the neutral standing pose over 500 ms
and enters IDLE. With `loop: true` it replays from the start at each end instead
of returning, until another motion command (gait / `T: 2` / a new clip) preempts
it. Clip ids/names come from `clips_manifest.json` (generated with `clips_all.h`).
| Key | Type | Description | Range |
| :----- | :--- | :--- | :---- |
| 'c' | int  | Clip id (index into FH_CLIPS[]) | 0..N-1 |
| 'loop' | bool | Replay continuously instead of playing once (optional) | default false |

**Example:** `{"T": 7, "c": 0}` *(play clip 0 once; out-of-range ids are ignored)*
**Example:** `{"T": 7, "c": 0, "loop": true}` *(loop clip 0 until preempted)*

---

### 8. List Clips (`T: 8`)
Query firmware for all compiled-in clips. The robot replies immediately over the
same WebSocket connection with the clip registry built from `FH_CLIPS[]` at runtime.
No parameters required.

**Example request:** `{"T": 8}`

**Example response:**
```json
{"clips":[{"id":0,"name":"lie down and stand up","ms":3000},
           {"id":1,"name":"one leg lift","ms":2042},
           {"id":2,"name":"tiny wiggle","ms":3000},
           {"id":3,"name":"wave","ms":1208},
           {"id":4,"name":"wiggle","ms":3000}]}
```

---

## 📤 Robot -> Dashboard (Telemetry)

### 10. System Status (`T: 10`)
| Key | Type  | Description |
| :-- | :---- | :--- |
| `s` | int | Current active FSM State (0-3) |
| `d` | array | ToF distance readings [FL, FR, RL, RR, Center] |
| 'a' | array | AMU array containing speed + gyroscope [Speed, Rotation x, Rotation y, Rotation z] |
| 'g' | int | Current gait mode of the robot |
| 'pc'| float | The current percentage of the movement (gait) accomplished |
| `e` | string or null | Error message observed (if any) |
| `pitch_deg` | float | Signed pitch tilt in degrees (nose up = positive), MPU6050 accel-derived |
| `roll_deg` | float | Signed roll tilt in degrees (right-side-down = positive), MPU6050 accel-derived |
| `upside_down` | bool  | Latched upside-down flag with hysteresis (flip > 150°, clear < 30°); the same boolean the firmware uses to auto-`setInverted` |
| `auto_invert_enabled` | bool | Current value of the `T:6` setter — `true` if the firmware is allowed to drive `isInverted` off the IMU. Mirrored so the app's toggle re-syncs on reconnect. |

**Example:** `{"T": 10, "s": 0, "d": [200, 200, 200, 200, 150], "a": [0.6, 50, 90, 15], "g": 1, "pc": 0.7, "e": null, "pitch_deg": 1.2, "roll_deg": -0.5, "upside_down": false, "auto_invert_enabled": true}`
**Note:** Broadcast every 100 ms (10 Hz) to every connected WebSocket client. The three IMU fields piggyback on this packet rather than running a separate stream — keeps connection bandwidth low.

---

## ⚠️ Safety Logic
1. **Timeout:** If no `T: 1` command is received for > 2 seconds while in `STATE_WALK`, the robot reverts to `STATE_IDLE`.
2. **Action Gate:** `STATE_ACTION` is ignored if battery voltage is under a certain threshold.

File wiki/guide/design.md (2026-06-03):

<!-- Sections below are suggestions, not requirements. Keep what's useful, drop or merge the rest. -->
# Design

## The concept

FaceHugger is a four-legged robot with an unsual stance and gait pattern. It is not built like a mammal (think about dogs or horses). Instead, its limbs are spread at 45° and it moves either like a crab, or with a diagonal trot.

On top of that, the FaceHugger can flip its legs upside down, in order to stand and walk on its back. 

To determine its orientation, we equipped it with multiple Time Of Flight sensors. But unfortunately, we couldn't make them work on time. 

A small IMU is connected, should you ever want to get precise gyroscopic measurements for movement.

Finally, we use a screen to display cute expressions.

## How a leg is built

Each leg is comprised of 3 links: the hip, connecting the leg to the body; the femur, connected to the hip; and the knee, connected to the femur. Each leg has 3 motors, 2 in the hip and 1 in the knee. This gives each leg 3 degrees of freedom.

The hip moves in yaw in respect to the body, the femur moves in pitch in respect to the hip, and the knee moves in pitch in respect to the femur.

## How a leg moves

Each joint moves the foot in a predictable way: the hip yaw swings the whole leg left or right, the femur pitch lifts or lowers the foot in an arc, and the knee pitch extends or retracts it. Walking gaits are built from coordinated sweeps of those two pitch joints, while yaw steers.

**Inverse kinematics** (IK) is the reverse problem: given a desired foot position in space, compute the three joint angles that reach it. For a 3-DOF leg, the hip and knee angles are solved geometrically (law of cosines on the two-link chain), and the shoulder yaw is found with `atan2` from the target's horizontal position relative to the body. This gives a closed-form solution with no iteration needed.

IK is fully implemented in the simulation pipeline (Python) and in the Blender rig (used by the animation exporter). The firmware, however, does not run IK at runtime. It works from pre-baked angle tables: gaits are fixed pose sequences, and animations are authored offline and exported as frame arrays. The vision of a closed-loop IK controller (where an IMU loop reads body tilt, computes corrective foot targets, and resolves them to servo angles in real time to keep the robot level) was designed but not implemented in the firmware within the scope of this project. The building blocks are all there; the runtime loop is the missing piece.

For the servo sign conventions and the exact coordinate frame, see [Reference → Conventions](../reference/conventions.md).

## Sizing & loads

!!! todo
    Why the links and servos are sized the way they are; how much weight a leg
    holds. Full torque model in
    [Reference → Torque analysis](../reference/simulation/torque-analysis.md).

The servos have a torque of 30 kgcm. This means they can, at full power, move a load of 30kg, 1cm away from the axis of rotation. This may seem a lot, but given a leg of total length, say 20 cm, the furthermost servo would be able to move a load of 1.5kg. We had to shorten the legs to the most we could, while keeping the flip gimmick.

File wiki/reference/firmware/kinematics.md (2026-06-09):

# Kinematics conventions

The URDF is the single source of truth for FaceHugger's kinematics. Every
consumer — PyBullet sim, Blender rig, firmware servo math, animation
exporter — is expected to agree with it. This page documents the
conventions baked into the URDF and walks through how the URDF is
generated from CAD and how PyBullet loads it.

For the CAD-side detail (the Fusion → URDF generator), see
[reference/animation/urdf-pipeline.md](../animation/urdf-pipeline.md).
For the firmware servo-angle convention (`translateToServo` + per-leg
CALIB), see [servo-conventions.md](servo-conventions.md).

## Convention quick-reference

**World frame**: `+X` right, `+Y` forward, `+Z` up.

**Leg naming**: `fl`, `fr`, `bl`, `br` everywhere in URDF, Python and
Blender. The firmware numbers legs `FR=0, FL=1, RR=2, RL=3`; `RR`/`RL`
are the same physical legs as `br`/`bl`. The translation lives at the
firmware boundary — never propagate `rr`/`rl` into Python or Blender.

**Joint names** in the URDF are `{leg}_link{1,2,3}_joint` (e.g.
`fl_link1_joint` for the front-left shoulder). The semantic mapping
`link1 = shoulder`, `link2 = hip`, `link3 = knee` lives in
`pybullet_sim.motor._joint_type_from_name`.

**Rest pose**: URDF `θ = 0` corresponds to each leg's Fusion mechanical
zero. Joint limits in the URDF are shifted by the Fusion `rest` value
so the range is symmetric about θ=0:

```
urdf_lower = fusion.min - fusion.rest
urdf_upper = fusion.max - fusion.rest
```

## Shoulder (link1) — yaw, Z axis

All four shoulders use a single uniform axis: `<axis xyz="0 0 1"/>`. A
positive shoulder angle rotates the leg counter-clockwise viewed from
above. The per-leg rest pose is encoded entirely in
`<joint><origin rpy="0 0 {rest_rad}"/>` — **not** in a per-leg axis
sign. This is *Convention A*. It means "+δ on every leg" rotates each
leg the same way around its own +Z; the rest already places each leg
in the right body quadrant.

The Fusion export only carries the FL leg's mechanical zero
(`Link1Revolute.limits_rad.rest`). The other three rests are derived:

| Leg | Body quadrant | Rest angle |
|---|---|---:|
| FL | -X +Y | -45° (−π/4) |
| FR | +X +Y | +45° (+π/4) |
| BR | +X -Y | +135° (+3π/4) |
| BL | -X -Y | -135° (−3π/4) |

Formula (see `urdf_gen.generate_urdf._shoulder_rest_for`):

```
FR = -FL
BR =  wrap_pi(FL + π)
BL = -wrap_pi(FL + π)
```

URDF shoulder limits are `[-90°, +90°]` for every leg (Fusion's
`[-135°, +45°]` shifted by `rest = -45°`).

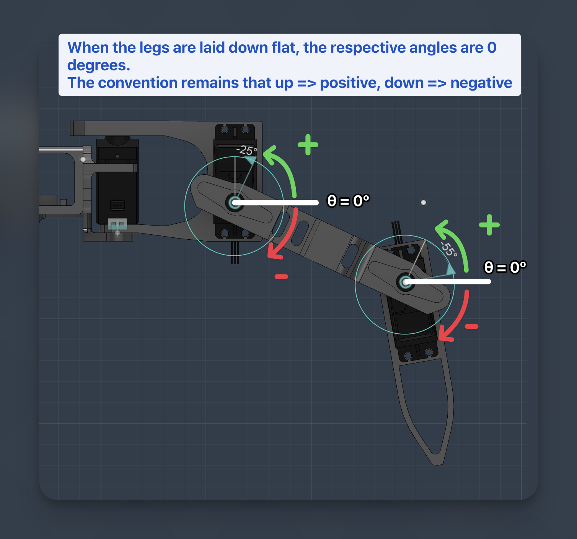
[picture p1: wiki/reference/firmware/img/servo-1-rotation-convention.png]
Shoulder rotation convention


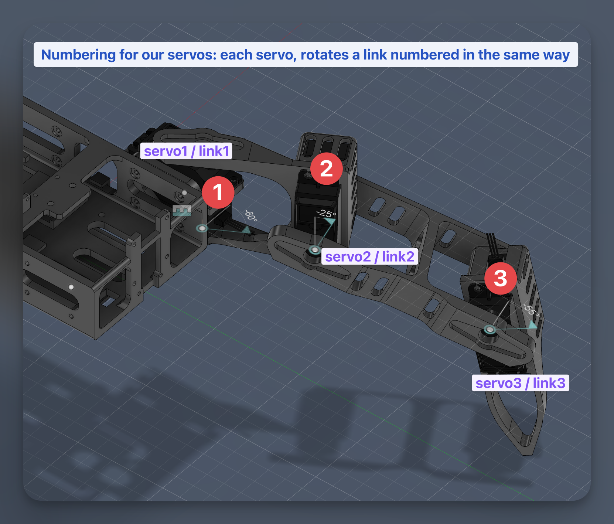
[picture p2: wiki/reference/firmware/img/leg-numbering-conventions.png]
Leg numbering and body-frame layout


## Hip (link2) and knee (link3) — pitch, Y axis

Both axes are along Y, with a per-side sign flip: `+Y` for the L pair
(FL, BR) and `-Y` for the R pair (FR, BL). The flip cancels out the
mirrored physical mounting of the servo horns between the L and R
brackets — so "horn-up = positive angle" describes the same physical
motion on every leg. Both rests are 0°: positive lifts the leg up,
negative drops it.

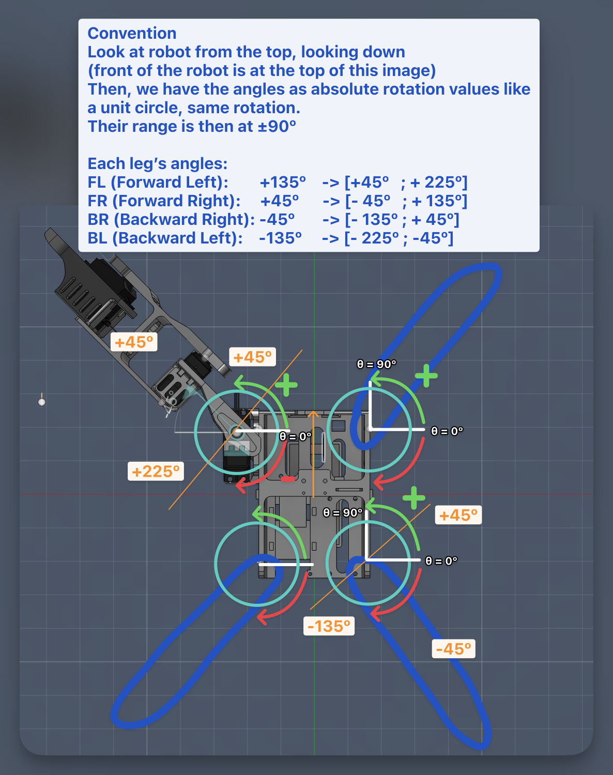
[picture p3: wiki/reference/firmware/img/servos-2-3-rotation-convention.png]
Hip / knee rotation convention


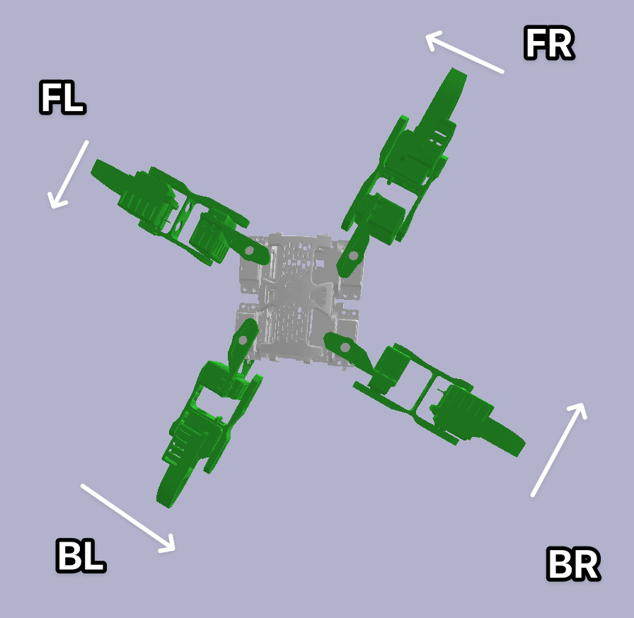
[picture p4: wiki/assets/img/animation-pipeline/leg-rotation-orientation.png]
Leg rotation orientation per side


## URDF generation

Entry point: `python code/facehugger.py urdf`, which invokes
`urdf_gen.generate_urdf`. Inputs:

- `code/simulation/generated/fusion_export.json` — Fusion's export
  (per-mesh `origin_shift_mm`, occurrence tree, joint axes and limits).
- `code/simulation/facehugger_config.yaml` — per-leg handedness
  (`side: L|R`), servo physical properties, the base-link mass extra.
  Per-leg `rpy_z_deg`, `shoulder_limits_deg`, and `shoulder_neutral_deg`
  are no longer in the yaml — they are derived from the JSON.

Output is `generated/facehugger.urdf` with one `<link>` per chassis
body and three per leg (`{leg}_link1`, `{leg}_link2`, `{leg}_link3`).
Twelve revolute joints total. A `<!-- LEG ASSEMBLY METADATA -->` comment
block near the top carries the leg-assembly-local landmark positions
(`BodyToLink1Point`, `Link1ToLink2Point`, `Link2ToLink3Point`,
`FootTip`); consumers read it via `pybullet_sim.urdf_io` rather than
re-opening `fusion_export.json`.

Every mesh has its vertices pre-shifted in CAD so that mesh-local
`(0,0,0)` is the link frame's origin (the next joint's pivot). The
primary `<visual><origin>` is therefore identity; placement happens via
the joint chain. STL `scale="0.001 0.001 0.001"` always — meshes are
in millimetres.

For the deep walk-through (mesh re-origin, mount-point landmarks,
combined-rule meshes, the servo-role assignment) see
[reference/animation/urdf-pipeline.md](../animation/urdf-pipeline.md).

## PyBullet runtime

`python code/facehugger.py sim` boots PyBullet from
`generated/facehugger.urdf` and drives it. The flow is:

1. `pybullet_sim.kinematics.build_config` parses the URDF: joint
   origins, axes, limits per leg; foot-tip position in link3 frame
   (with `Ry(π)` applied for the R pair to mirror the shared
   `leg_upper`/`leg_lower` meshes); per-leg `hip_axis_sign` and
   `knee_axis_sign` from the URDF `<axis>` Y component.
2. `pybullet_sim.scene.connect_and_setup` connects, loads `plane.urdf`
   and `facehugger.urdf` at `(0, 0, body_height + 0.02)`, then builds
   the `joint_name → joint_idx` map.
3. `pybullet_sim.motor.reset_to_stance` bends each leg to the stance
   pose derived from the firmware's NEUTRAL (through `translateToServo`
   with SIL CALIB=90 → servo_angles_to_joint_targets, cached in
   `pybullet_sim.kinematics._NEUTRAL_HIP_KNEE`). Without this step the
   robot stays in rest pose — legs horizontal, the "starfish" layout —
   which is the visual that a flat URDF importer that doesn't apply joint
   state produces.
4. `pybullet_sim.motor.apply_leg_pose` then sends matching motor
   targets so gravity doesn't pull the bent joints back to zero.

After settling, `run_stand` idles the sim; for clips and gaits the
compiled firmware SIL (`firmware_sil.sil_bridge`) computes servo targets
and drives the joints through `apply_joint_targets`.

The body height (`cfg.body_height`) is computed by `build_config` as
the lowest foot Z in the neutral pose, so the body spawns clear of the
floor. With the current CAD it's ≈ 0.12 m; spawn lifts another 2 cm to
absorb collision penetration.

## Convention checklist for new code

- Shoulder axis is `+Z` global, never per-leg sign-flipped.
- Joint angles are in radians end-to-end; degrees only at yaml or UI
  boundaries.
- URDF `θ = 0` is the Fusion rest pose — not "leg straight along ±X".
- Limits come from the URDF (already shifted relative to rest); don't
  re-impose them in code.
- Leg IDs in URDF/Python/Blender are `bl`/`br`. Map to the firmware's
  `rl`/`rr` only at the firmware boundary.
- Link lengths and mount positions are read from the URDF, never
  hardcoded. The Fusion CAD revision can change at any time; anything
  pinned in Python source goes stale.

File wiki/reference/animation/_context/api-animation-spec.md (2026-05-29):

<!--
WIKI-MIGRATION REFERENCE COPY
Original path:  code/simulation/docs/API_ANIMATION_SPEC.md
Original kind:  spec
Copied on:      2026-05-21
Status:         unreviewed
Maps to:        reference/animation/blender-rig.md
-->

> **Reference material.** Verbatim copy of `code/simulation/docs/API_ANIMATION_SPEC.md` kept in `_context/`
> as source for the published wiki page. Edit the parent wiki page, not
> this file. The original at `code/simulation/docs/API_ANIMATION_SPEC.md` is still canonical; this file is
> scaffolding the user will delete manually once the wiki pages exist.
<!--
CONSISTENCY-CHECK 2026-05-21
Verified against: feat/wiki-setup @ 0a1a138
- [ok]    13-bone rig + uniform bone-local-Z (align_roll) + _bone_endpoints_world_mm tail-projection all match animation/scripts/urdf_to_blender_rigged.py (ARMATURE_NAME="FaceHuggerRig", base_link + 12 link bones).
- [drift] §2/§3 describe FK shoulder + IK chain_count=2 with foot target parented to {leg}_link1. Current rig drives link1 yaw ANALYTICALLY via a scripted driver (rotation_euler[2]) + foot_ik/foot_local indirection; foot empties are named `foot_target_{leg}` (FOOT_TARGET_FMT), not `{leg}_foot_target`. The "rotate shoulder → drag foot" manual-FK workflow no longer matches.
- [drift] §6's "Current implementation" note is correct: real conversion is fh_clip_panel.py `_frame_to_servo` = scale-from-NEUTRAL (0.6667) + per-leg translateToServo, sourced from animation/convention.json, parity-locked by animation/scripts/test_servo_parity.py. The `offset_deg + direction*degrees(z)` model below it is the never-built .gait pipeline.
- [stale] §6/§7 servo_mapping.yaml + .gait export + gait_to_c.py + validator do not exist in repo (no servo_mapping.yaml, no export_gait.py/gait_to_c.py, no *.gait files). Superseded by the .js / clips_all.h angle-space route (doc/animation-pipeline/onboard-clip-player-design.md).
- [stale] DSS-M15S 0–270° / 135° mid-range is wrong for current hardware: code/firmware/src/shared/config.h uses 180° servos (MIN_PULSE 150 / MAX_PULSE 600). Neutral is per-leg per-joint (convention.json neutral_joint_deg), not a flat 135.
- [todo]  Links to doc/gait-design/specs/* point at the superseded tree (CLAUDE.md: gait-design superseded by animation-pipeline). servo_id 0..11 numbering is still a PROPOSAL (SERVO_ID_CONVENTION.md); firmware uses LEG_SERVO_CHANNEL[leg][servo] in config.h.
-->
# API_ANIMATION_SPEC — animator-facing reference

How to load the FaceHugger rig in Blender, pose it, and export the
result toward the firmware playback engine. Aimed at the animator
working day-to-day, not at someone re-implementing the import pipeline.

For the import pipeline internals, see
[`animation/scripts/urdf_to_blender_rigged.py`](../../../animation/scripts/urdf_to_blender_rigged.py)
and the surrounding [README](../../../animation/scripts/README.md).
For the joint-angle convention authority, see
[`MERGE_AND_CONVENTION.md`](MERGE_AND_CONVENTION.md). For servo
numbering, see
[`animation/SERVO_ID_CONVENTION.md`](../../../animation/SERVO_ID_CONVENTION.md).

---

## 1. Loading the rig

```bash
python code/simulation/facehugger.py blender --rigged
```

Builds a fresh scene with the FaceHugger model + posable rig in
Blender 5.x. Default Blender version is 5.1; override via
`--blender-version 5.2` or set `BLENDER_BIN` for a non-standard
install path.

Headless smoke-test variant (CI / scripting):

```bash
python code/simulation/facehugger.py blender --rigged \
    --headless --save /tmp/fh_rigged.blend
```

The script reads
[`code/simulation/generated/facehugger.urdf`](../generated/facehugger.urdf)
+
[`code/simulation/generated/fusion_export.json`](../generated/fusion_export.json)
+ STLs from
[`code/simulation/generated/exported_meshes/`](../generated/exported_meshes/).
Re-export from Fusion + regenerate the URDF before re-running if the
CAD has moved. The rig itself is rebuilt from scratch on every run —
nothing persistent in the `.blend`.

---

## 2. Rig structure

13 bones, all named to match URDF link names exactly (lowercase):

```
Armature "FaceHuggerRig"
├── base_link              (root, fixed — represents the chassis)
├── fl_link1               (FL shoulder; URDF axis = world +Z, bone-local Z after align_roll)
│   └── fl_link2           (FL hip;      URDF axis = world +Y, bone-local Z after align_roll)
│       └── fl_link3       (FL knee;     URDF axis = world +Y, bone-local Z after align_roll)
├── fr_link1
│   └── fr_link2
│       └── fr_link3
├── bl_link1
│   └── bl_link2
│       └── bl_link3
└── br_link1
    └── br_link2
        └── br_link3
```

After `EditBone.align_roll(joint.axis)`, **bone-local Z is the URDF
joint axis for every joint uniformly** — including the per-side ±Y
sign on hip/knee (URDF `<axis>0 -1 0</axis>` for FR/BL). This means:

- Pose-mode rotation lives entirely on `rotation_euler[2]` for every
  servo. No per-joint axis branching anywhere.
- A positive `rotation_euler.z` rotates the leg "up" the same way on
  both L and R sides.

**Why this works** — `align_roll(target)` only achieves
`bone-local Z = target` when the target is perpendicular to the bone's
Y axis (head→tail); when it isn't, Blender projects the target into
the plane ⊥ Y and the resulting bone-Z drifts from the URDF axis
(≈13° on `*_link1` because of the joint origin's Z lift, ≈23° on
`*_link3` because of the foot tip's Y component).
[`_bone_endpoints_world_mm`](../../../animation/scripts/urdf_to_blender_rigged.py)
fixes this at rig-build time by projecting each bone's tail onto the
plane perpendicular to its joint axis. After projection, bone-Y is ⊥
joint axis, `align_roll` is exact, and the
`rotation_euler[2] == joint angle` contract above is literal. The bone
is therefore a rotation control whose Y is **not** along the limb on
`*_link1` / `*_link3`; mesh geometry comes from `attach_visuals`'
explicit `matrix_world` and is unaffected.

Constraints (auto-applied at rig-build time):

| Constraint | On which bones | Effect |
|---|---|---|
| `LIMIT_ROTATION` (use_limit_z) | all 12 joint bones | Clamp pose rotation to URDF `<limit lower upper>`. |
| `IK` (chain_count=2, use_stretch=False) | each `*_link3` (knee) | Solve hip+knee to reach `{leg}_foot_target`. Shoulder stays FK. |
| `lock_ik_x = lock_ik_y = True`, `ik_stiffness_x/y = 1.0` | all 12 joint bones | Force IK solver to rotate around bone-local Z only — no lateral bending. |

---

## 3. Animation workflow (the physical 3-servo recipe)

The rig matches how the 3 servos per leg actually work in hardware:

1. **FK shoulder (servo 1, world Z yaw)** — rotate `{leg}_link1` in
   pose mode by hand. Aims the leg laterally. Servo 1 is independent
   of the foot target.
2. **IK hip + knee (servos 2 + 3, both pitch)** — drag the
   `{leg}_foot_target` Empty. The IK constraint solves the hip + knee
   rotations to bring the foot to the empty's position. Shoulder
   doesn't move (chain_count=2 excludes it).
3. **Foot target follows the shoulder.** The foot target is parented
   to `{leg}_link1` via `parent_type='BONE'` — no driver, no manual
   re-positioning when you rotate the shoulder. Animator workflow:
   rotate shoulder → drag foot.

Why not `chain_count=3` (shoulder included in IK)? The combination of
"foot parented to link1" + "link1 in IK chain" creates an unstable
loop (IK rotates link1 → foot moves with link1 → IK iterates against
a moving target → ~180 mm of rest-pose drift). chain=2 is the stable
combination for this rig.

If you ever need full 3-DOF IK without the FK shoulder, run
`facehugger.py blender --rigged --` and pass `--ik-chain 3` — but
that requires un-parenting the foot target manually before the rig
is usable.

---

## 4. Neutral pose

The rest pose has every bone at `rotation_euler = (0, 0, 0)`. This is
the URDF θ=0 pose AND the splayed standing stance:

| Leg | Shoulder yaw (world frame) |
|---|:---:|
| FL | -45° |
| FR | +45° |
| BL | -135° |
| BR | +135° |

All hips and knees at 0°. The per-leg shoulder offset is encoded in
the URDF `<joint><origin rpy>` per Convention A — it does **not**
appear as a non-zero Blender rotation value. See
[`MERGE_AND_CONVENTION.md` §0/§3](MERGE_AND_CONVENTION.md) for the
authoritative spec.

The first and last frame of every gait cycle must return to this
pose so the firmware can transition between gaits without blending.
See `doc/gait-design/specs/blender-rig-and-export.md` §4 and
`gait-file-format.md` §1.

---

## 5. Bake before export

IK-solved angles are NOT stored in FCurves — only the foot target's
keyframes are. Before running the gait export script, **bake the
visual pose into per-bone FCurves**:

**GUI**: Pose Mode → menu Pose → Animation → Bake Action

```
☑ Visual Keying        (evaluates the IK solve at each frame)
☑ Clear Constraints    (optional — removes the IK after baking;
                        recommended once the gait is final)
☑ Overwrite Current Action
Frame range: match your animation
```

**Python** (run inside Blender Scripting workspace, or via a script
launched with `--python`):

```python
import bpy

bpy.ops.nla.bake(
    frame_start=bpy.context.scene.frame_start,
    frame_end=bpy.context.scene.frame_end,
    only_selected=False,
    bake_types={"POSE"},
    visual_keying=True,
    clear_constraints=False,
    use_current_action=True,
)
```

After baking, every joint bone has explicit `rotation_euler[2]`
keyframes at every frame — that's what the export script reads.

---

## 6. Angle conversion (Blender → servo)

> 📌 **Current implementation lives in `fh_clip_panel.py` `_frame_to_servo`** —
> scale-from-N (2/3, from `animation/convention.json`) + per-leg
> `translateToServo` (matches firmware `tickGait`, locked by the
> [parity test](../../../animation/scripts/test_servo_parity.py)). The
> `offset_deg + direction*degrees(blender_z)` model below describes the
> earlier `servo_mapping.yaml`/`.gait` pipeline; it is retained for
> reference and is being superseded by the design in
> [`doc/animation-pipeline/onboard-clip-player-design.md`](../../../doc/animation-pipeline/onboard-clip-player-design.md)
> (see §3.2 for the pre-scaled math-space rule, §3.1 for one-shot +
> hold-at-end semantics, §6 for the firmware contract). Phase-1 path
> (today) is the `.js` browser console; Phase-2 will be the bundled
> `clips_all.h` + `playClip(id)` over WS.

The export script reads `pose.bones["{leg}_link{N}"].rotation_euler[2]`
for each frame and converts to servo PWM degrees:

```
servo_deg = offset_deg + direction * degrees(blender_z_rad)
servo_deg = clamp(servo_deg, min_deg, max_deg)
```

Per-bone fields come from
[`servo_mapping.yaml`](../../../doc/gait-design/specs/blender-rig-and-export.md#6-servo-mapping-config)
(authoritative schema in
[`blender-rig-and-export.md` §6](../../../doc/gait-design/specs/blender-rig-and-export.md#6-servo-mapping-config)):

- **`offset_deg`** — servo PWM angle when Blender bone is at 0 rad
  (the URDF rest pose). Default 135° (mid of the DSS-M15S 0–270°
  range). Calibrated per assembled robot.
- **`direction`** — 1 or -1, hardware-calibration-only (kinematic L/R
  asymmetry is already absorbed into bone roll via `align_roll`).
  Default 1 everywhere; flip to -1 only after seeing a specific servo
  drive its joint backward on the assembled robot.
- **`min_deg` / `max_deg`** — post-conversion PWM safety clamps,
  separate from the URDF kinematic limits (which the rig enforces via
  `LIMIT_ROTATION`).
- **`servo_id`** — firmware-side per-PWM-channel index. The default
  numbering uses URDF leg ordering (`fl=0..2, fr=3..5, bl=6..8,
  br=9..11`); see
  [`SERVO_ID_CONVENTION.md`](../../../animation/SERVO_ID_CONVENTION.md)
  for the proposal status and how it aligns (or not) with the
  firmware's `SERVO_CONFIG[]` ordering.

---

## 7. Gait file output

The end product of the export pipeline is a `.gait` JSON file —
sparse keyframes per servo, time in milliseconds, angles in servo
degrees. Format spec:
[`doc/gait-design/specs/gait-file-format.md`](../../../doc/gait-design/specs/gait-file-format.md).
Firmware playback engine spec:
[`doc/gait-design/specs/esp32-playback-engine.md`](../../../doc/gait-design/specs/esp32-playback-engine.md).

Validation: every track's first and last keyframe must equal the
neutral-pose servo angle (typically 135°), tracks must cover all 12
servos, and angles must stay within `min_deg`/`max_deg`. The
validator catches these before the gait file ships to firmware
compilation (`gait_to_c.py`).

---

## 8. Troubleshooting

| Symptom | Likely cause | Fix |
|---|---|---|
| Leg bends laterally when dragging foot target | IK X/Y locks not applied (somehow) | Re-run `facehugger.py blender --rigged` to rebuild rig from scratch. Check pose-bone properties: `lock_ik_x = lock_ik_y = True`. |
| Foot doesn't follow shoulder rotation | Foot target lost its parent (got un-parented in pose mode) | Re-parent: select foot target → Object Properties → Relations → Parent: Armature, Bone: `{leg}_link1`, Type: Bone. Then move it to the rest position. |
| IK rotates the shoulder | `--ik-chain 3` was passed | Re-run with default `--ik-chain 2`, or unparent the foot target. |
| Mesh "drifts" in viewport vs PyBullet | URDF was regenerated but the rig wasn't rebuilt | Re-run `facehugger.py blender --rigged`. The rig is rebuilt from scratch on every invocation. |
| Joint goes past the URDF limit | `LIMIT_ROTATION` constraint disabled | Check pose bone constraints in the Properties panel. |
| Foot target starts in the wrong place | `Link3TipAxis` missing from `fusion_export.json` (CAD not re-exported) | Re-export from Fusion. Falls back to a hardcoded value in the meantime — animator-visible offset of ~50–60 mm in some legs. |

---

## 9. Cross-references

- [`animation/scripts/urdf_to_blender_rigged.py`](../../../animation/scripts/urdf_to_blender_rigged.py) — implementation
- [`animation/scripts/README.md`](../../../animation/scripts/README.md) — script-level overview
- [`animation/SERVO_ID_CONVENTION.md`](../../../animation/SERVO_ID_CONVENTION.md) — servo numbering
- [`code/simulation/docs/MERGE_AND_CONVENTION.md`](MERGE_AND_CONVENTION.md) — joint angle convention
- [`doc/gait-design/specs/blender-rig-and-export.md`](../../../doc/gait-design/specs/blender-rig-and-export.md) — `servo_mapping.yaml` schema, export details
- [`doc/gait-design/specs/gait-file-format.md`](../../../doc/gait-design/specs/gait-file-format.md) — `.gait` JSON format
- [`doc/gait-design/specs/esp32-playback-engine.md`](../../../doc/gait-design/specs/esp32-playback-engine.md) — firmware-side consumer

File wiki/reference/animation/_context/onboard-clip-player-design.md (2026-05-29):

<!--
WIKI-MIGRATION REFERENCE COPY
Original path:  doc/animation-pipeline/onboard-clip-player-design.md
Original kind:  design
Copied on:      2026-05-21
Status:         unreviewed
Maps to:        reference/animation/fhc-format.md
-->

> **Reference material.** Verbatim copy of `doc/animation-pipeline/onboard-clip-player-design.md` kept in `_context/`
> as source for the published wiki page. Edit the parent wiki page, not
> this file. The original at `doc/animation-pipeline/onboard-clip-player-design.md` is still canonical; this file is
> scaffolding the user will delete manually once the wiki pages exist.
<!--
CONSISTENCY-CHECK 2026-05-21
Verified against: feat/wiki-setup @ 0a1a138
- [todo]  Whole design is unimplemented: no tickClip/playClip/CLIPS[]/clips_all.h anywhere in code/firmware/src/ (grep empty). Matches CLAUDE.md ".fhc engine implementation has not started" / Phase B.
- [stale] Proposed CMD_PLAY_CLIP at "next free T:6 with {c:<id>}" — slot T:6 is now TAKEN. data.h has CMD_ACTION_SELECTION=6; network.cpp:128 dispatches it (payload {a:1}=INVERT_ROBOT → invertRobot), and STATE_ACTION=2 maps to spinalCord.wallFlip() (network.cpp:84, spinal_cord.cpp:86). A clip player would need a different command number / to share STATE_ACTION with wallFlip.
- [ok]    2/3 pre-scale claim holds: convention.json scale=0.6667; firmware tickGait (spinal_cord.cpp:142) + translateToServo (spinal_cord.cpp:212,330) confirm the math-space→servo split.
- [ok]    STATE_ACTION slot exists and is real (data.h STATE_ACTION=2), as the design assumes — though it is now occupied by wallFlip, not "empty" as §2 states.
- [drift] §2 context pins firmware @ origin 3899ebc and "STATE_ACTION dispatch is empty / CMD_POSE=3 unhandled". Current main: STATE_ACTION→wallFlip is wired; CMD_POSE=3 still defined (data.h:8). Context snapshot is stale.
- [drift] §11/§2 reference PR #72 as the exporter PR; per urdf-conventions cross-check PR #72 was actually a generate_urdf link-fix PR. Verify PR mapping before acting on §11.
-->
# On-board one-shot animation clip player + bundled export format

**Status:** design — awaiting user review before implementation planning
**Date:** 2026-05-19
**Author:** Marcus + Claude (brainstorming)

## 1. Goal & scope

Author arbitrary animations in Blender (e.g. "wiggle"), export them in a
single bundled header, and play any of them on the robot on demand. The
robot plays the clip once on its exported timeline, then **freezes and holds
the final pose**. Selection is by clip id over the existing WebSocket API,
modelled on how gaits are selected today.

**In scope**

- A bundled, pre-scaled, registry-style export header (`clips_all.h`).
- A firmware one-shot clip player on the existing empty `STATE_ACTION` slot.
- One API command to select/play a clip by id (mirrors `CMD_GAIT_MODE`).
- Phase 1 path that needs zero firmware (reuse existing `to_js`).

**Non-goals (YAGNI)**

- No looping clips, no blending between clips, no clip queue.
- No steering/direction coupling (clips are canned, unlike gaits).
- No auto-return to neutral after a clip (a separate existing command does
  that — e.g. set gait none / rest).
- No dynamic upload of clips at runtime; clips are compiled in (like
  `GAITS[]`).
- No change to the existing gait engine behaviour.

## 2. Context (as of 2026-05-19)

- **Firmware** `feat/hardware-integration-milestone-2` @ origin `3899ebc`
  (clean). Angle-space gait engine: `NEUTRAL[]` (raw math-space deg),
  `GAITS[]` presets pre-scaled to 2/3 of JS values, `tickGait()` on
  `STATE_WALK` applies an inline per-leg `translateToServo` switch →
  `setJointAngles()`. `STATE_ACTION` dispatch is empty. `CMD_POSE=3` is
  defined but unhandled.
- **Animation** `feat/animation-pipeline` — local tip `b7e85cb`, **24
  commits ahead of origin (unpushed)**. Two-layer exporter
  (`_sample_clip` → `to_csv`/`to_c_header`/`to_js`) wired via
  `FH_OT_export_clip` to `animation/exported_gaits/<clip>/`.
  `animation/convention.json` (`neutral_joint_deg`, `scale` 0.6667,
  `channels`) is the single source of truth and is byte-identical to the
  firmware `NEUTRAL[]`/channels in `3899ebc`.
- **PR #72** (`feat/animation-pipeline` → `main`) is open but **stale**
  (last update 2026-05-12); it predates all the export work. Not load-bearing
  for this design; see §11.

## 3. Locked decisions

1. **One-shot, hold-at-end.** `playClip(id)` runs the clip once on its
   `t_ms` timeline; past the last frame it holds the final pose (keeps
   writing the last frame's servo angles) and stays in `STATE_ACTION`. No
   loop, no auto-return.
2. **Pre-scaled math-space header.** The 2/3 scale-from-NEUTRAL is applied
   at **bake time** (exporter), exactly as `GAITS[]` presets are
   "pre-scaled to 2/3". The header carries math-space joint degrees. The
   firmware applies **only** `translateToServo` at runtime — identical
   convention to `tickGait`.
3. **Clip player is the gait engine's structural twin.** Same shapes:
   `CLIPS[]` registry ↔ `GAITS[]`; `playClip(id)` ↔ `setGait(g)`;
   `tickClip()` ↔ `tickGait()`; shared `translateToServo()` helper used by
   both.
4. **`convention.json` stays the single source of truth** for
   neutral/scale/channels/leg-order; the header is generated from it; docs
   updated to state the pre-scale rule explicitly.
5. **Single motion owner (mutual-exclusion invariant).** At most one of
   {a gait, a clip} drives the servos at any instant. This is *structural*,
   not a runtime check: the firmware has one `robotState`, and `update()`
   ticks exactly one handler per loop — `STATE_WALK→tickGait`,
   `STATE_ACTION→tickClip`. Transitions are explicit and pre-emptive:
   - `playClip(id)` → set `STATE_ACTION` (any running gait stops being
     ticked immediately; it is not "paused", it simply ceases).
   - any move/gait command (`CMD_MOVE`/`CMD_GAIT_MODE`) → set `STATE_WALK`
     (a running clip ceases).
   - `playClip` while already in `STATE_ACTION` → restart that clip
     (newest command wins; no blending, no queue).
   There is deliberately no concurrency to manage because two motion
   sources never coexist.

## 4. Architecture

Two branches + the app:

- **`feat/animation-pipeline`** (exporter): add a bundled converter
  `to_clips_header()` + an "export all clips" path. Existing `to_js`
  unchanged (Phase 1).
- **New branch off origin/`3899ebc`** (firmware): extract a shared
  `translateToServo()` helper from `tickGait`; add `CLIPS[]`, `tickClip()`,
  `playClip(id)`, one command case.
- **App / webpage**: a row of buttons. Phase 1 sends the `to_js`-generated
  stream; Phase 2 sends `playClip(id)`.

```
feat/animation-pipeline                      branch off origin 3899ebc (firmware)
───────────────────────                      ───────────────────────────────────
Blender rig (fh_clip_panel)
 └ _sample_clip  (raw joint deg/frame)
    └ NEW to_clips_header()  ── 1 file ──►  clips_all.h
       · scale-from-N (2/3) applied             FhClip FH_CLIPS[]= {name,frames,n,dur}
       · reordered to firmware LegId             FhClipFrame {t_ms, a[12]}
       · math-space deg                                 │
 └ to_js() ─ browser ─ WS:81 ─┐ (Phase 1)               ▼
                              │            ┌───────────────────────────────────┐
                              └─ servo ───►│ SpinalCord                         │
                                           │  CMD_PLAY_CLIP → playClip(id)      │
                                           │  STATE_ACTION  → tickClip()        │
                                           │     interp frame → translateToServo│◄─ shared
                                           │     → setJointAngles()             │   helper
                                           │  STATE_WALK → tickGait() unchanged │◄─ (refactor)
                                           └───────────────────────────────────┘
                                                           │ Leg→Servo→PCA9685
App buttons: Phase 1 = run to_js stream | Phase 2 = send playClip(id)
```

## 5. Export format — `clips_all.h` (the contract to hone)

One generated header, all clips bundled, indexed by id = registry index.

```c
#ifndef FH_CLIPS_ALL_H
#define FH_CLIPS_ALL_H
#include <stdint.h>

/* Auto-generated by FH Clip Panel — do not edit.
 * a[12] = PRE-SCALED math-space joint degrees (2/3 scale-from-NEUTRAL
 * applied at bake). Order is firmware LegId: FR,FL,RR,RL × (sh,th,kn).
 * Firmware applies ONLY translateToServo() at runtime (see tickGait). */

typedef struct { uint16_t t_ms; float a[12]; } FhClipFrame;
typedef struct {
    const char*        name;
    const FhClipFrame* frames;
    uint16_t           frame_count;
    uint16_t           duration_ms;   /* == frames[frame_count-1].t_ms */
} FhClip;

#define FH_CLIP_COUNT 2
static const FhClipFrame fh_clip_wiggle[] = {
    {   0, { /*FR sh,th,kn*/ ..., /*FL*/ ..., /*RR*/ ..., /*RL*/ ... }},
    {  33, { ... }},
    /* ... */
};
static const FhClipFrame fh_clip_bow[] = { /* ... */ };

static const FhClip FH_CLIPS[FH_CLIP_COUNT] = {
    { "wiggle", fh_clip_wiggle, 42, 1386 },
    { "bow",    fh_clip_bow,    18,  594 },
};
#endif
```

Format rules (all enforced by the exporter, documented in
`convention.json` neighbours):

- **Angle space:** math-space joint degrees, 2/3 scale-from-`NEUTRAL`
  already applied. Firmware never scales.
- **Leg/axis order:** `a[12]` is firmware `LegId` order (FR=0, FL=1,
  RR/BR=2, RL/BL=3), each leg `(shoulder, hip/thigh, knee)`. The exporter
  remaps from Blender `JOINT_BONES` order (`fl,fr,bl,br`) using
  `convention.json`. This `fl/fr/bl/br` ↔ `FR/FL/RR/RL` mapping is the
  known footgun (see CLAUDE.md leg-naming note) and is asserted in tests.
- **Timing:** `t_ms` from clip start, taken from the existing
  `_sample_clip` frame/fps math. `duration_ms` = last frame's `t_ms`.
- **Id:** index into `FH_CLIPS[]`. Stable within a build; the app learns
  names→ids from the same generated artifact (also emit a tiny
  `clips_manifest.json` for the app).
- Frame rate is whatever Blender authored (no resampling); firmware
  linearly interpolates between bracketing `t_ms` (see §6).

## 6. Firmware design (branch off origin `3899ebc`)

1. **Refactor (non-behavioural):** lift `tickGait`'s per-leg
   `translateToServo` switch into
   `ServoTriple translateToServo(uint8_t legId, float sh, float th, float kn)`.
   `tickGait` calls it; gait output is bit-identical (regression-tested).
2. **`CLIPS[]`** = `#include "clips_all.h"`; the registry is the generated
   `FH_CLIPS[]`.
3. **`playClip(uint8_t id)`**: validate `id < FH_CLIP_COUNT`; set
   `currentClip_`, `clipStartMs_ = millis()`, enter `STATE_ACTION`.
   Invalid id → ignored (logged), like the gait bound-check.
4. **`tickClip()`** on `STATE_ACTION`:
   - `elapsed = millis() - clipStartMs_`.
   - If `elapsed >= duration_ms` → **hold**: use the last frame's `a[12]`,
     `translateToServo` per leg, `setJointAngles`, return (stay in
     `STATE_ACTION`; do not advance, do not loop).
   - Else find the two frames bracketing `elapsed` by `t_ms`, linearly
     interpolate the 12 angles, `translateToServo` per leg,
     `setJointAngles`.
   - Cursor cached (monotonic) to avoid O(n) scan each tick.
5. **API:** add `CMD_PLAY_CLIP` (next free `T`, e.g. `T:6`) with `{ "c":
   <id> }`, mirroring `CMD_GAIT_MODE`'s validation shape; dispatch →
   `playClip(c)`. Update `code/API_SPEC.md`. (Alternative considered:
   reuse `CMD_POSE=3` — rejected: `POSE` has different documented
   semantics; a clean new command is clearer and lower-risk.)

## 7. App / webpage

Minimal: a button per clip, labels/ids from `clips_manifest.json`.
- **Phase 1:** button runs that clip's `to_js` stream over the existing
  socket (already functional today).
- **Phase 2:** button sends `{ "T":6, "c": <id> }`.

Existing `code/remote-control-app/MyApp` (socket + GaitControl screen) is
the natural home; a throwaway single HTML page is acceptable for first
validation.

## 8. Phasing

- **Phase 1 — now, zero firmware.** Use existing `to_js`; validate clips,
  convention, timing, and the button UX from the browser. No new code
  required to start.
- **Phase 2 — additive firmware.** Refactor + `to_clips_header()` +
  `tickClip()` + `CMD_PLAY_CLIP`. Robot becomes self-contained; same
  buttons switch to `playClip(id)`.

Phase 2 does not begin until Phase 1 has validated at least one real clip
on hardware.

## 9. Data flow

Blender pose → `_sample_clip` (raw math-space deg/frame) → `to_clips_header`
(scale-from-N 2/3, reorder to LegId, emit `clips_all.h` +
`clips_manifest.json`) → compiled into firmware → `playClip(id)` →
`tickClip()` (interpolate → `translateToServo` → `setJointAngles`) →
`Leg` → `Servo` → PCA9685.

## 10. Error handling & edge cases

- Unknown/out-of-range clip id → ignore + serial log (matches gait
  bound-check behaviour). Robot stays in current state.
- Empty clip (0 frames) → exporter refuses to emit it; firmware treats
  `frame_count==0` as no-op.
- Single-frame clip → immediately holds that pose.
- `elapsed` between frames → linear interpolation; before first frame →
  first frame; after last → hold last.
- `millis()` wrap (~49 days) → out of scope (robot uptime ≪ that);
  documented assumption.
- Command arriving mid-clip → newest command wins (re-`playClip` restarts;
  `setGait`/move pre-empts back to gait engine).
- Clip angle outside servo range → exporter clamps to [0,180] after
  `translateToServo` parity check; flagged at bake (reuse heatmap warning).

## 11. Branch / PR coordination

- Exporter changes land on `feat/animation-pipeline` (already 24 ahead;
  push + refresh **PR #72**, or open a focused PR — decide at plan time).
- Firmware changes land on a **new branch off origin/`3899ebc`** (not off
  our discarded local work), PR'd into `feat/hardware-integration-milestone-2`.
- The two are independent until integration; the only shared contract is
  `clips_all.h`'s format + `convention.json`. No cross-branch merge needed.
- Implementation therefore splits naturally into **two independent plans**:
  (A) exporter `to_clips_header` + manifest on `feat/animation-pipeline`;
  (B) firmware refactor + `tickClip` + `CMD_PLAY_CLIP` on the new firmware
  branch. (A) can ship and be validated via Phase 1 before (B) starts.

## 12. Convention & documentation updates

- Add the pre-scale rule to `animation/convention.json`'s doc neighbour
  and `code/simulation/docs/API_ANIMATION_SPEC.md`: *"clip headers are
  pre-scaled math-space; firmware applies only translateToServo."*
- Note the `fl/fr/bl/br` ↔ `FR/FL/RR/RL` reorder in the exporter and in
  `MERGE_AND_CONVENTION.md` cross-reference.
- `clips_all.h` carries the rule in its banner comment.

## 13. Testing strategy

- **Exporter:** unit test `to_clips_header` on a fixture clip — frame
  count, `t_ms` monotonic, `duration_ms`, leg reorder correctness, scale
  applied once. Determinism (byte-stable output).
- **Firmware (native Unity):** `translateToServo` helper parity vs the
  pre-refactor inline switch (gait regression: identical servo output for
  a sampled set). `tickClip` interpolation math (bracketing, lerp, hold,
  single-frame). Round-trip: a known clip frame through
  `to_clips_header`-equivalent values → `translateToServo` matches
  `_frame_to_servo` from `fh_clip_panel.py` within ≤1°.
- **On hardware:** Phase 1 `to_js` of one clip; then Phase 2 same clip via
  `playClip` — visually identical motion + holds final pose.

## 14. Open questions / risks

- **Command number:** `T:6` proposed; confirm no collision in
  `API_SPEC.md` evolution.
- **Header size:** dense per-frame × clips could grow flash; mitigation:
  author at modest fps, `float`→`int16` deciDegrees if needed (deferred —
  measure first).
- **PR #72 disposition:** refresh vs new focused PR — decided at plan
  time, not blocking design.

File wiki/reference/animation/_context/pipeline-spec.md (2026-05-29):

<!--
WIKI-MIGRATION REFERENCE COPY
Original path:  code/simulation/docs/PIPELINE_SPEC.md
Original kind:  spec
Copied on:      2026-05-21
Status:         unreviewed
Maps to:        reference/animation/urdf-pipeline.md
-->

> **Reference material.** Verbatim copy of `code/simulation/docs/PIPELINE_SPEC.md` kept in `_context/`
> as source for the published wiki page. Edit the parent wiki page, not
> this file. The original at `code/simulation/docs/PIPELINE_SPEC.md` is still canonical; this file is
> scaffolding the user will delete manually once the wiki pages exist.
<!--
CONSISTENCY-CHECK 2026-05-21
Verified against: feat/wiki-setup @ 0a1a138
- [ok]    §3 mount-point keys (LegMountPointFL/FR/BR/BL) match facehugger_config.yaml legs[].mount_point exactly (yaml lines 74-87).
- [ok]    §1/§7/§10 side L/R + rpy_z assignment matches yaml: FL=L, BR=L, FR=R, BL=R; R-pair axis negate + limit negate-and-swap implemented at generate_urdf.py:1039/1042.
- [drift] §4 zero-angle: spec says "0° = leg pointing along -X (FL base)". Current generator uses Convention-A per-leg shoulder rest derived from fl_rest_rad = -π/4 (-45°), not 0° (generate_urdf.py:166-190 _shoulder_rest_for). Spec predates Convention A; cross-ref MERGE_AND_CONVENTION.md §0/§4.
- [drift] §7/§4 "Phase T (joint capture) ... reads limits directly from CAD export, no manual entry in yaml" is framed as future; facehugger_config.yaml still carries shoulder_limits_deg override (yaml line 63). Generator prefers CAD-sourced with yaml fallback — matches §7 prose but the "no manual entry" aspiration is not the current state.
- [drift] §10 last row references simulate.py shoulder_neutral_deg=0° per leg — superseded by the per-leg Convention-A rest above; treat as historical.
- [todo]  Doc is the CAD-decisions spec; mostly stable. Phase B: reconcile the 0°-zero-angle framing with Convention A before publishing.
-->
# FaceHugger URDF Pipeline — CAD Decisions & Spec

This document captures all grilling answers and design decisions for the
Claude Code plan adaptation. Use this as the authoritative reference when
updating the export script, generator, and config.

---

## 1. Leg assignment and mesh pairing

The base leg model (L mesh) points along **-X** at zero joint angle.
The R mesh is the XZ-plane mirror of L — it naturally points along **+X**.

| Leg | Mesh | Orientation | Quadrant | rpy_z_deg |
| --- | ---- | --- | --- | --- |
| FL  | L | base | -X, +Y | 0° |
| BR  | L | 180° Z flip | +X, -Y | 180° |
| FR  | R | base | +X, +Y | 0° |
| BL  | R | 180° Z flip | -X, -Y | 180° |

**Diagonal pairs:**
- FL + BR share the L mesh
- FR + BL share the R mesh

The 180° Z flip for the back leg of each pair rotates around the leg's own
mount point (`LegMountPointXX`) — the mount point stays fixed, the leg flips
in place.

---

## 2. Mirror plane for R mesh

`Link1R` and `MotorMountR` were mirrored through the **XZ plane of the
FaceHuggerLegAssembly** origin. `BodyToLink1Point` has local position
`(11.97, 0.0, -4.2)` — Y=0, so it lies exactly on the XZ plane. The mirror
is invariant at that point. No separate plane or construction point needed.
Re-origining math works cleanly: subtracting `BodyToLink1Point` from R
vertices gives the same shoulder-axis-at-origin result as for L.

---

## 3. Mount point naming

| File | Point name | Purpose |
| --- | --- | --- |
| `FlexibleSkeleton` (body) | `LegMountPointFL` | Body-side attachment, FL corner |
| `FlexibleSkeleton` (body) | `LegMountPointFR` | Body-side attachment, FR corner |
| `FlexibleSkeleton` (body) | `LegMountPointBR` | Body-side attachment, BR corner |
| `FlexibleSkeleton` (body) | `LegMountPointBL` | Body-side attachment, BL corner |
| `MotorMount` (bracket) | `LegMountFixedPoint` | Bracket-side attachment point |

`LegMountFixedPoint` on each bracket coincides with its corresponding
`LegMountPointXX` on the body when assembled. The URDF generator uses
`LegMountPointXX` as the shoulder joint origin. `LegMountFixedPoint` is
for CAD alignment verification only.

All 4 `LegMountPointXX` are at the **same Z height** on the body.

The yaml `mount_point` keys reference `LegMountPointFL` etc. — update the
yaml to use these new names.

---

## 4. Shoulder joint zero and limits

**Zero angle definition:** 0° = leg pointing along -X (FL base orientation).
This comes directly from the Fusion joint definition.

**Fusion limits for FL** (source of truth, L mesh): `lower = -105°, upper = +45°`

From FL's limits, derive the other legs by checking which direction is
"forward" (+Y) for each leg:

| Leg | Zero points  | Forward swing | Backward swing | URDF lower | URDF upper |
| --- | --- | --- | --- | --- | --- |
| FL  | -X | +45° | -105° | **-105°**  | **+45°** |
| BR  | +X (flipped) | -45° | +105° | **-45°** | **+105°**  |
| FR  | +X | -45° | +105° | **-45°** | **+105°**  |
| BL  | -X (flipped) | +45° | -105° | **-105°**  | **+45°** |

**Pattern:** legs pointing -X (FL, BL) keep FL limits as-is.
Legs pointing +X (FR, BR) get limits negated and swapped.

These values come from the Fusion revolute joint on `Link1Revolute`. Once
Phase T (joint capture) lands, the generator reads them directly from the
CAD export — no manual entry in yaml.

---

## 5. Link2 and Link3 orientation

Link2 and Link3 are **shared meshes** (no L/R split yet). Their visual
orientation per leg is handled by `mesh_rpy` in the URDF generator via
the `R_L1` rotation — same as the current pipeline. Do **not** rotate
Link2/Link3 bodies in Fusion CAD. Leave them as-is.

---

## 6. Body components (base_link)

The following are chassis-fixed and bake into `QuadrupedBody.stl` when
`FlexibleSkeleton:1` is exported as a single STL:

- `QuadrupedBody` (main frame)
- `LipoCage` (sub-body, treated as part of chassis)
- All electronics components (hidden, excluded by `VISIBLE_ONLY = True`)

`MotorMount` and `MotorMountR` now live inside `FaceHuggerLegAssembly`,
**not** inside `FlexibleSkeleton`. The old `LegMountXX:1` occurrences in
`FlexibleSkeleton` are removed.

---

## 7. Revolute joints in Fusion

Three revolute joints are now defined inside `FaceHuggerLegAssembly`:

| Joint name | Links | Axis |
| --- | --- | --- |
| `Link1Revolute` | MotorMount → Link1L | BodyToLink1Axis  |
| `Link2Revolute` | Link1L → Link2L | Link1ToLink2Axis |
| `Link3Revolute` | Link2L → Link3L | Link2ToLink3Axis |

Limits are set in Fusion with rest angles. Phase T (A3 in the plan) captures
these via `collect_joints()` into `fusion_export.json`. The generator prefers
CAD-sourced limits over yaml, with yaml as override fallback.

---

## 8. R mesh base orientation

When `Link1R` is placed in FR position with `rpy_z_deg = 0°`, it naturally
points along **+X** — the XZ mirror flips the X direction. No additional
rotation needed for FR base placement. Same for BL at `rpy_z_deg = 180°`.

---

## 9. Rotation center for 180° flip

The 180° Z rotation for BR and BL rotates **around the leg's own mount
point** (`LegMountPointBR` / `LegMountPointBL`). The mount point stays
fixed in world space — the leg geometry flips in place around that point.

---

## 10. Summary: what changes in each file

| File | Change |
| --- | --- |
| `facehugger_config.yaml` | Update `mount_point` keys to `LegMountPointXX`; add `side: L/R` per leg; set `rpy_z_deg` per table above; set per-leg shoulder limits per table above |
| `ExportBodiesToURDF.py`  | Fix `MESH_EXPORTS` for moved bracket; add L/R STL rules; add `collect_joints()` |
| `generate_urdf.py` | Per-side mesh selection; per-leg limits from table; consume CAD joints when present |
| `simulate.py` | `shoulder_neutral_deg = 0°` for all legs; per-leg limits from config |

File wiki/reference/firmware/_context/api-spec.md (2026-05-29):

<!--
WIKI-MIGRATION REFERENCE COPY
Original path:  code/API_SPEC.md
Original kind:  spec
Copied on:      2026-05-21
Status:         unreviewed
Maps to:        reference/firmware/api.md
-->

> **Reference material.** Verbatim copy of `code/API_SPEC.md` kept in `_context/`
> as source for the published wiki page. Edit the parent wiki page, not
> this file. The original at `code/API_SPEC.md` is still canonical; this file is
> scaffolding the user will delete manually once the wiki pages exist.
<!--
CONSISTENCY-CHECK 2026-05-21
Verified against: feat/wiki-setup @ 0a1a138
- [ok]    Transport: WebSocket port 81 (network.cpp:10 WebSocketsServer(81)); T-values match data.h CommandType (MOVE=1,STATE=2,POSE=3,CALIBRATE=4,GAIT_MODE=5,ACTION_SELECTION=6,TELEMETRY=10). T:4 calibrate keys id/servo_id/a + LEG_SERVO_CHANNEL[id][servo_id] confirmed in network.cpp:90-98.
- [drift] T:1 Manual Movement key is wrong. Doc table says key 'd' (int, IDs 0..6). Firmware reads doc["dir"] (network.cpp:105) and app sends {T:1, dir: ...} (api-messages.tsx). The wire key is "dir", not "d".
- [drift] Direction values are strings, not int IDs. app/api-types.tsx DirectionVector = "FW"/"BW"/"FW_R"/"FW_L"/"BW_R"/"BW_L"/"R"/"L"/"STOP". Doc's numbered 0..6 vector list does not match; also app adds R/L (in-place turn) not in doc's enumeration.
- [drift] Gait Mode IDs disagree. Doc: TROT=0, CRAB=1, CRAWL=2. Real GaitType (movements.h): NONE=0, WALK=1, TROT=2, CRAB=3; app GaitMode TROT=2/CRAB=3. There is no CRAWL; T:5 'g' is validated against [GAIT_NONE..GAIT_CRAB] in network.cpp:119.
- [drift] FSM has a 5th state not in doc's T:2 table: STATE_REST=4 (data.h). network.cpp CMD_STATE maps IDLE→rest(), WALK→walk(), ACTION→wallFlip(); guard only allows newState<=STATE_FAILSAFE so REST isn't reachable via T:2.
- [todo] T:3 body-pose (h/p/r), T:10 telemetry shape, and §Safety timeout/voltage gate are not implemented in network.cpp's handler (no T:1-with-h/p/r, no telemetry emit) — left for Phase B to confirm against firmware loop/sensors.
-->
# FaceHugger API Specification v1.1

This document defines the JSON-based communication protocol between the **Web Dashboard** and the **ESP32 Firmware**.

## 📡 Transport Layer
- **Protocol:** WebSocket (Bi-directional)
- **Port:** 81
- **Format:** Minified JSON
---

## Direction vector type
The direction vector of the robot
- **FW (id 0):** Forward vector (0.0, 1.0)
- **BW (id 1):** Backward vector (0.0, -1.0)
- **FR (id 2):** Front right vector (1.0, 1.0)
- **FL (id 3):** Front left vector (-1.0, 1.0)
- **BR (id 4):** Backward right (1.0, -1.0)
- **BL (id 5):** Backward left (-1.0, -1.0)
- **STOP (id 6):** Stop, user finished walking so we send a message to stop and finish the action (0.0, 0.0)

## Gait Mode Type 
The gait mode the robot is currently in
- **TROT (id 0):** Trot gait mode
- **CRAB (id 1):** Crab gait mode
- **CRAWL (id 2):** Crawl gait mode

## Action Mode Type
The action mode type
- **INVERT ROBOT (id 0):** Send a message to invert the robot 

## 📥 Dashboard -> Robot (Commands)
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

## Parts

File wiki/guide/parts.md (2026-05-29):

# Parts & Materials

This page details everything required to build a FaceHugger v7.5 quadruped. It
covers the 3D-printed chassis components, the required electronics and power
distribution hardware, and a complete breakdown of every screw and fastener used
in the assembly.

## Bill of materials (summary)

| Category | Item | Qty | Notes |
|---|---|---|---|
| Electronics | ESP32 (upesy_wroom) | 1 | Main microcontroller and Wi-Fi Access Point |
| Electronics | PCA9685 Multiplexer | 1 | 16-channel PWM driver for the servos |
| Electronics | DSS 230mg Servo | 12 | Metal gear, high-torque (requires servo horns) |
| Electronics | I²C Sensors & UI | 5 | 1× OLED screen, 1× IMU, 3× ToF sensors |
| Power | 2S LiPo Battery | 1 | Main power source |
| Power | Buck Converter | 1 | Steps LiPo voltage down to 5V for logic |
| Power | BMS Module | 1 | Battery Management System for protection |
| Power | 2200µF 35V Capacitor | 1 | Wired in parallel to multiplexer to absorb inrush current |
| Fasteners | Metric Screws & Nuts | 148 | M2 to M4 (see full breakdown below) |
| Fasteners | Ball Bearings | 12 | Fits inside the printed joints |
| Printed | FaceHugger Chassis | 18 | Frame, legs, and mounts (see full breakdown below) |
| Misc | Zip Ties & Elastic Bands | 8 | Cable management and foot traction |

## Electronics

The electronic ecosystem is split into two domains: high-current muscle (servos)
and low-current brains (logic).

**Microcontroller**

- 1× ESP32 (upesy_wroom), handles WebSocket communication, Inverse Kinematics,
  and gait state machines

**Actuators**

- 12× DSS 230mg metal-gear servos, 3 per leg (Hip, Thigh, Knee)
- 12× compatible servo horns (one per servo)

**Power distribution**

- 1× 2S LiPo battery
- 1× BMS (Battery Management System), sits between the LiPo and the rest of
  the power chain for protection
- 1× Step-down Buck Converter, 5V output for logic boards
- 1× 2200µF 35V electrolytic capacitor, wired in parallel to the PCA9685 to
  absorb inrush current and prevent logic brownouts

!!! tip
    Use terminal blocks (Domino blocks) to split the raw LiPo current to the
    servos directly, bypassing the PCA9685 power traces. The PCA9685 traces are
    not rated for the combined stall current of 12 servos.

**Peripherals (I²C bus)**

- 1× 128×64 OLED screen
- 1× IMU (Inertial Measurement Unit)
- 3× Time-of-Flight (ToF) distance sensors

**Cabling**

- Female-to-Female jumper wire spools
- Custom spliced I²C cable trees, 4 trees (VCC 3.3V, GND, SDA, SCL), each
  with 1 female connector on the ESP32 side splitting to 3 female connectors
  on the peripheral side

## Hardware & fasteners

!!! warning
    Always insert hex nuts into their printed retaining slots **before** driving
    any screws. Once a component is installed the slots are inaccessible.

### Master fastener count

| Size | Variant | Qty |
|---|---|---|
| M2 | M2×4 screws | 6 |
| M2 | M2×10 screws | 4 |
| M2 | Hex nuts | 4 |
| M2.5 | M2.5×2 screws | 2 |
| M2.5 | M2.5×5 screws | 3 |
| M2.5 | M2.5×6 screws | 11 |
| M2.5 | M2.5×8 screws | 16 |
| M2.5 | Hex nuts | 16 |
| M3 | M3×8 screws | 24 |
| M3 | M3×12 screws | 32 |
| M3 | Hex nuts | 44 |
| M4 | M4×12 screws | 12 |
| M4 | Hex nuts | 12 |

### Fasteners by assembly step

| Component | Fasteners required | Notes |
|---|---|---|
| Mounts (×4) | 16× M2.5×8, 16× M2.5 hex nuts | Attach the main leg mounts to the body shell |
| Hip joints | 12× M4×12, 12× M4 hex nuts, 4× M3×8, 4× M3 hex nuts | Heavy load-bearing joints |
| Thigh joints | 16× M3×12, 4× M3×8, 20× M3 hex nuts | |
| Knee joints | 16× M3×12, 4× M3×8, 20× M3 hex nuts | |
| Servo horns (×12) | 12× M3×8 | Attaches printed links to servo output shafts |
| Bridges | 7× M2.5×6 | Internal chassis sensor mounts |
| OLED screen | 4× M2×10, 4× M2 hex nuts | |
| ESP32 | 1× M2.5×5 | |
| ToF sensors (×3) | 6× M2×4 | |
| IMU | 2× M2.5×2 | |
| PCA9685 Multiplexer | 4× M2.5×6 | |
| Buck Converter | 2× M2.5×5 | |

## Printed parts

All parts are designed to be printed without supports where possible. Specific
print settings (infill, wall count, material) are documented in
[3D Printing](printing.md).

!!! warning "Left/Right mirroring"
    Pay close attention to L/R mirroring requirements when slicing the leg
    components. Printing two identical sides instead of a mirrored pair is a
    common mistake that will require a full reprint.

**Body components**

| Part | Qty |
|---|---|
| Shell (main chassis) | 1 |
| LiPo cage | 1 |
| Leg mounts | 4 |
| Bridge mounts (internal sensor structures) | 2 |

**Leg components (print 4 sets)**

| Part | Qty (per set) | Qty (total) | Notes |
|---|---|---|---|
| Link 1 (Hip) | 1 | 4 | Check L/R orientation |
| Link 2 (Thigh) | 1 | 4 | |
| Link 3 (Knee / Foot) | 1 | 4 | |

## Tools required

| Tool | Use |
|---|---|
| Hex drivers / Allen keys (M2, M2.5, M3, M4) | Driving all socket head screws |
| Soldering iron & solder | BMS, Buck Converter, and I²C cable trees |
| Wire strippers & crimping tool | Custom length servo cables and Dupont connectors |
| Needle-nose pliers | Seating hex nuts into tight printed pockets |
| Multimeter | Verifying 5V Buck Converter output and checking for short circuits before power-on |

## Key components

This section gives a plain-language introduction to the more complex components
used in FaceHugger. If you are already familiar with embedded electronics, skip
ahead to [Electronics](#electronics).

### ESP32

The ESP32 is the brain of the robot. It is a small, low-power microcontroller
with a dual-core processor, built-in Wi-Fi, and a large number of configurable
I/O pins. Unlike a Raspberry Pi, it has no operating system. It runs a single
compiled C++ program in a continuous loop, which is exactly what you want for
hard real-time control of 12 servos simultaneously.

In FaceHugger, the ESP32 handles everything: it creates the Wi-Fi hotspot,
receives commands from the app over WebSockets, runs the gait state machine, and
drives the PCA9685 over I²C.

### PCA9685: PWM Multiplexer

Servos are controlled by a PWM signal (Pulse Width Modulation), a precise
pulse sent up to 50 times per second whose width encodes the target angle. The
ESP32 has a limited number of hardware PWM channels and cannot reliably generate
12 independent, jitter-free servo signals on its own while also running Wi-Fi and
gait math.

The PCA9685 solves this by offloading the PWM generation entirely. The ESP32
sends a single I²C command ("set channel 4 to 1500µs") and the PCA9685 handles
the precise timing for all 16 channels independently, freeing the ESP32 to focus
on higher-level logic.

### DSS 230mg Servos

A servo is a self-contained actuator: a DC motor, a gearbox, a position sensor,
and a control circuit all in one package. You send it a PWM pulse and it moves
to the corresponding angle and holds it against external force.

The DSS 230mg are **metal-gear, high-voltage digital servos**. Metal gears matter
here because the hip and thigh joints sustain significant shock loads every time a
foot strikes the ground, and plastic gears would strip within hours.

FaceHugger uses 3 servos per leg, one for each joint (Hip, Thigh, Knee), for
12 servos total.

### 2S LiPo Battery

LiPo (Lithium Polymer) batteries offer a very high energy density, making them
the standard choice for mobile robotics. A **2S** pack contains two cells wired in
series, giving a nominal voltage of 7.4V and a fully charged voltage of 8.4V.

!!! danger "LiPo safety"
    LiPos are not like AA batteries. Mishandling them (over-discharging,
    puncturing, shorting, or charging without a proper LiPo charger) can cause
    fire. Always store them at storage voltage (~3.8V per cell) when not in use,
    never leave them charging unattended, and inspect the pouch for swelling before
    each use. A swollen LiPo must be safely discharged and disposed of immediately.

### BMS: Battery Management System

The BMS sits between the LiPo and the rest of the electronics and acts as an
automatic safety gate. It monitors cell voltage and current in real time and
cuts the circuit if it detects:

- **Over-discharge**: cell voltage dropping below a safe threshold (permanently
  damages LiPo cells)
- **Overcharge**: cell voltage exceeding safe limits (fire risk)
- **Short circuit**: a sudden current spike indicating a wiring fault

Skipping the BMS to save space is a common and dangerous mistake. Without it, a
single wiring error or a over-discharged battery has nothing preventing a
thermal runaway.

### Buck Converter

The LiPo outputs between 7.4V and 8.4V depending on charge state. The ESP32,
PCA9685, OLED, IMU, and ToF sensors all run on 3.3V or 5V logic. Feeding raw
LiPo voltage into any of these will instantly destroy them.

The Buck Converter is a switching voltage regulator that efficiently steps the
LiPo voltage down to a stable 5V output regardless of the battery's charge state.
"Efficiently" is important here, because a linear regulator would do the same job but
would waste the excess voltage as heat, which is unacceptable in a sealed chassis
drawing significant current.

### 2200µF Capacitor

When multiple servos move simultaneously, they draw a large burst of current in
a very short time. This sudden demand can cause the supply voltage to dip
momentarily (a **brownout**), which can reset the ESP32 mid-gait or corrupt I²C
communication with the PCA9685.

The capacitor acts as a local energy reservoir: it charges slowly from the supply
and discharges instantly into the circuit when a current spike occurs, smoothing
out the voltage dip before it reaches the logic boards. It is wired in parallel
with the PCA9685's onboard capacitor to increase the total reserve.

### IMU: Inertial Measurement Unit

The IMU (an MPU-6050) combines a 3-axis accelerometer and a 3-axis gyroscope on
a single I²C chip. It measures the robot's orientation and angular velocity in
real time. We didn't have the time to implement the software for it but in FaceHugger, 
its primary role would have been to detect when the robot has been
flipped upside-down, and trigger the `STATE_FAILSAFE` state to cut movement and
switch the OLED to the confused expression.

### ToF Sensors: Time-of-Flight

ToF sensors measure distance by emitting an infrared laser pulse and timing how
long it takes to reflect back from a surface. Three sensors are mounted on the
body bridges, giving the robot basic spatial awareness of its immediate
surroundings. Unlike ultrasonic sensors, ToF sensors have a very narrow beam and
high precision at short range, making them well suited for detecting obstacles at
leg-height. Just like the IMU, we didn't have the time to implement the software for them.

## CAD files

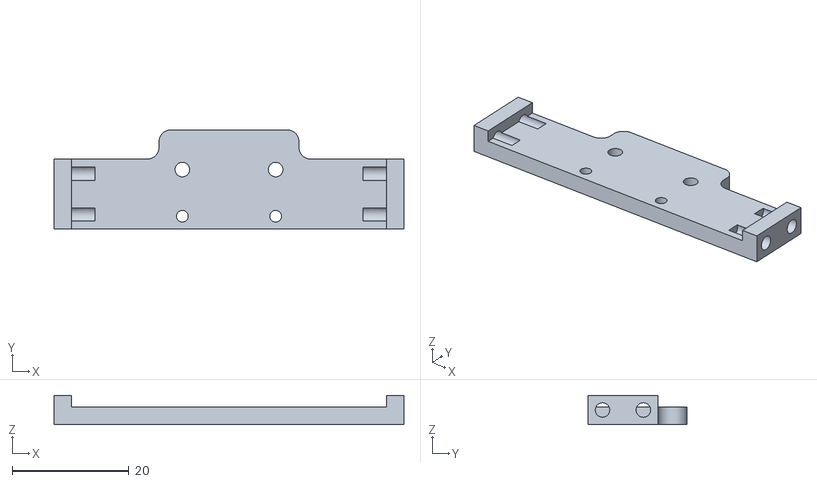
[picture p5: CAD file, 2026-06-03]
cad/body/MiddleBridge.stl
60.0 x 17.0 x 5.00

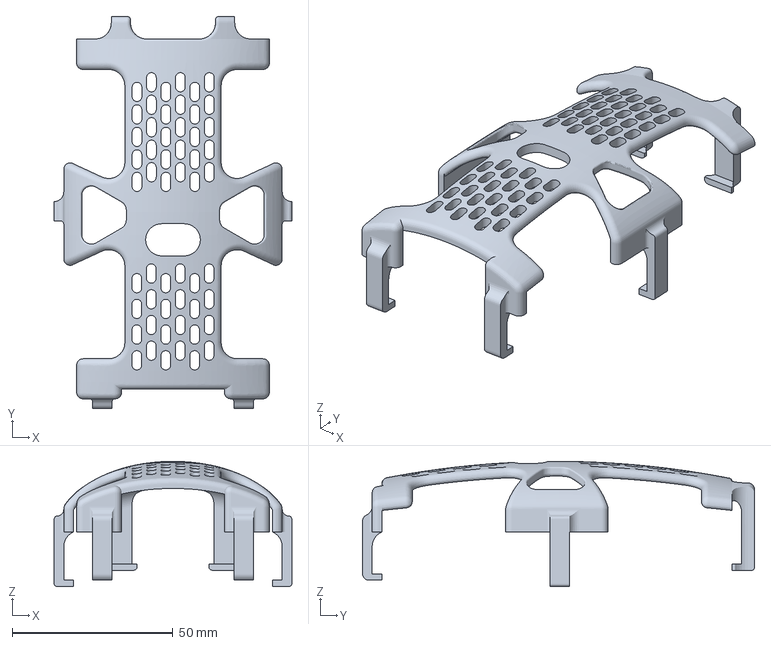
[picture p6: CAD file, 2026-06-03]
cad/body/prusa/ShellPrint.3mf
74.0 x 122.0 x 39.0 mm

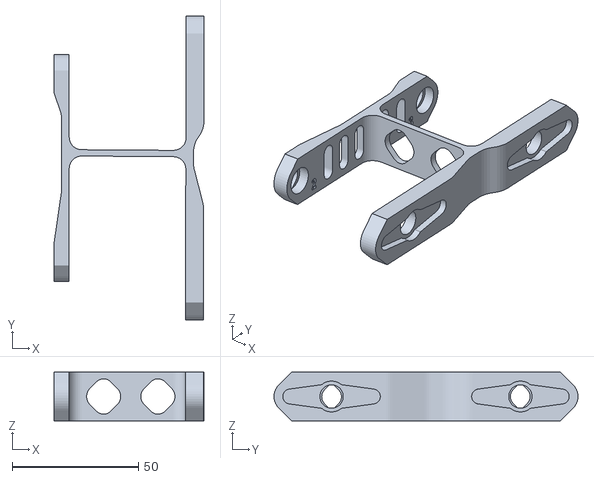
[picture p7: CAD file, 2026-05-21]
cad/leg/Link2.stl
59.3 x 120.2 x 19.2

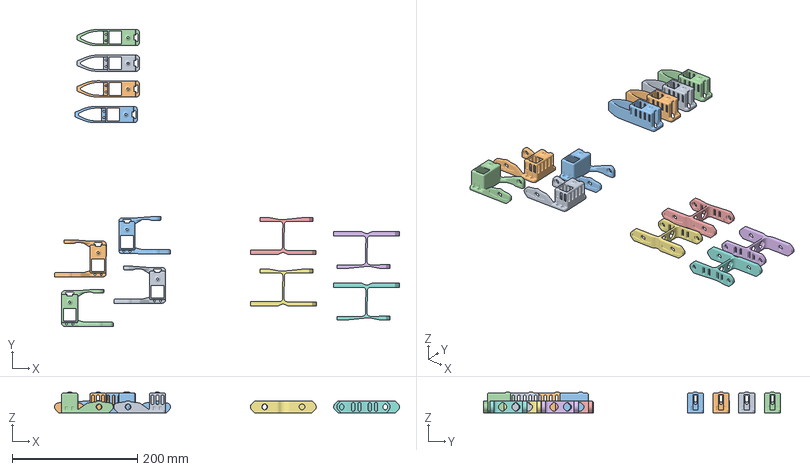
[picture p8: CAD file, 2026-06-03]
cad/leg/prusa/All4Legs3Plates.3mf
551.3 x 474.6 x 33.2 mm
Link1L.stl
Link1R.stl
Link2.stl
Link3.stl

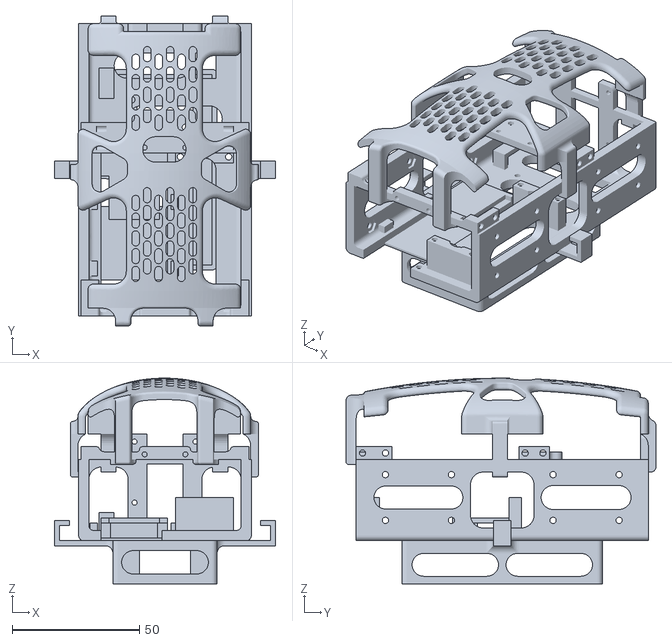
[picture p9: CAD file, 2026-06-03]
code/simulation/generated/exported_meshes/QuadrupedBody.stl
87.0 x 122.0 x 81.0

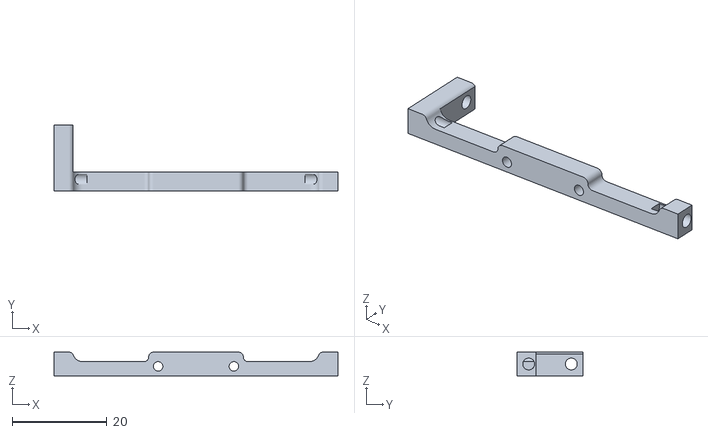
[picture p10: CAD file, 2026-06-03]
cad/body/BehindBridge.stl
60.0 x 14.0 x 5.00

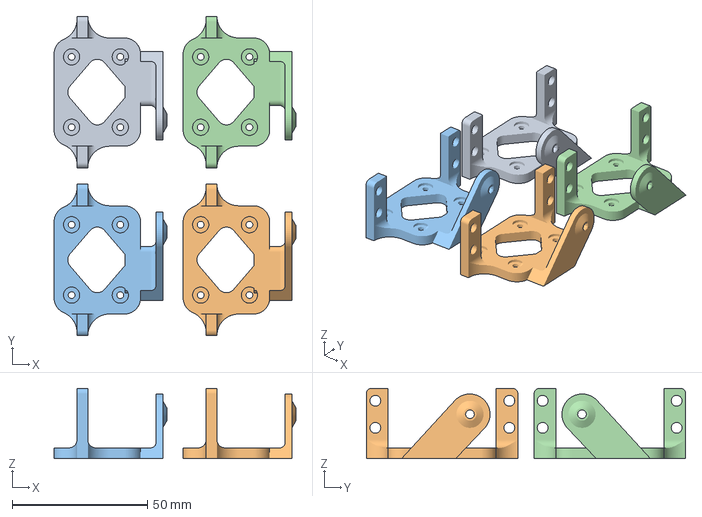
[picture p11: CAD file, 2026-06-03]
cad/body/prusa/HipMount.3mf
89.4 x 118.0 x 26.0 mm
HipMount.stl x 4

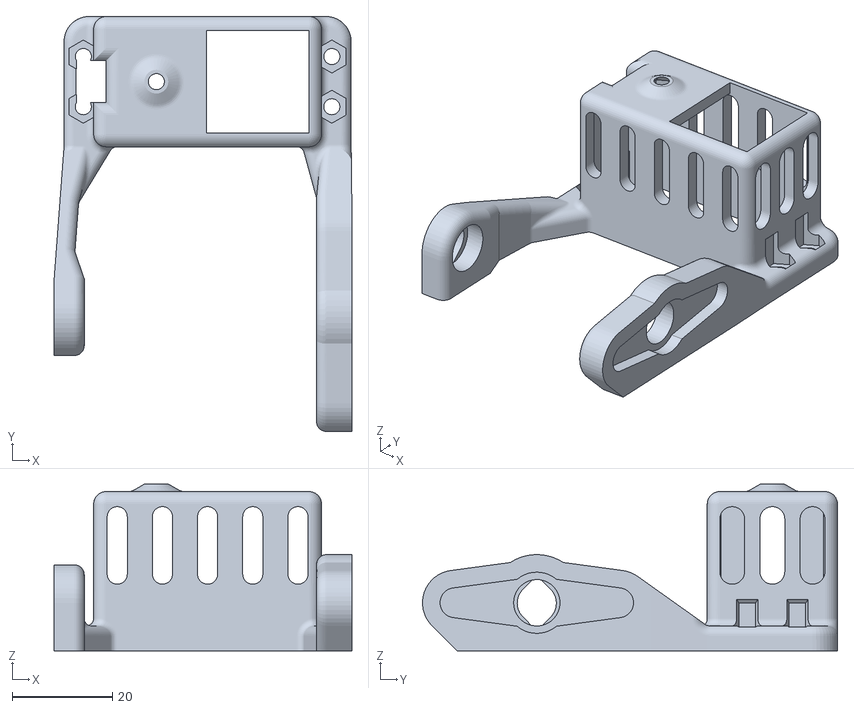
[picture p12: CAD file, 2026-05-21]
cad/leg/Link1L.stl
59.3 x 82.7 x 33.3

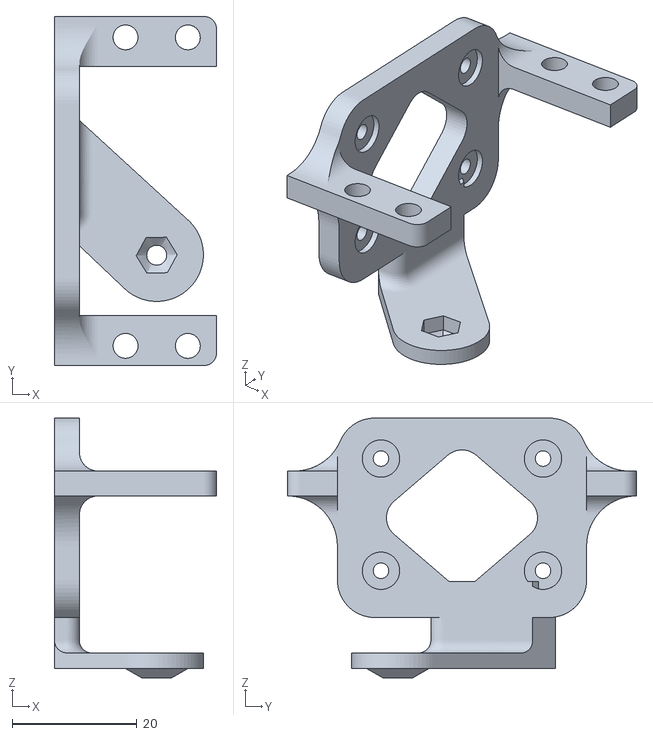
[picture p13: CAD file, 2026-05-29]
cad/body/HipMount.stl
26.0 x 56.0 x 41.7

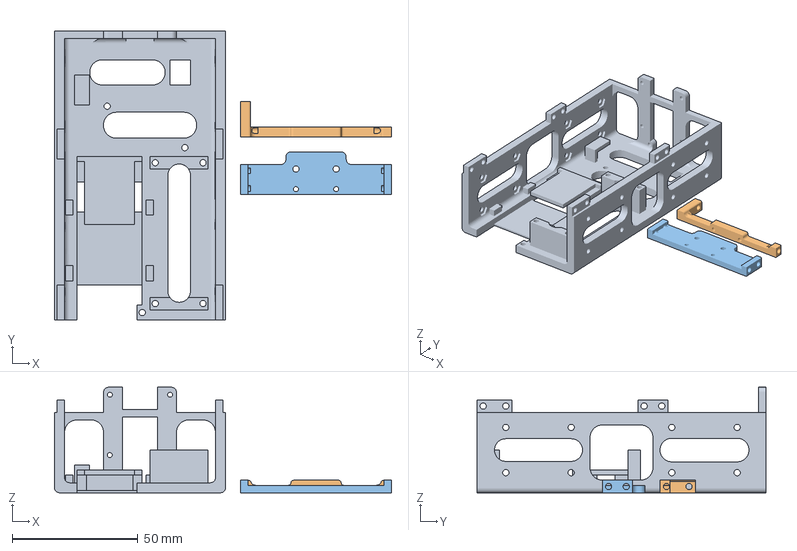
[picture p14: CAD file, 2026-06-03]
cad/body/prusa/BodyAndBridges.3mf
134.0 x 115.0 x 42.0 mm
BodySkeleton.stl
BehindBridge.stl
MiddleBridge.stl

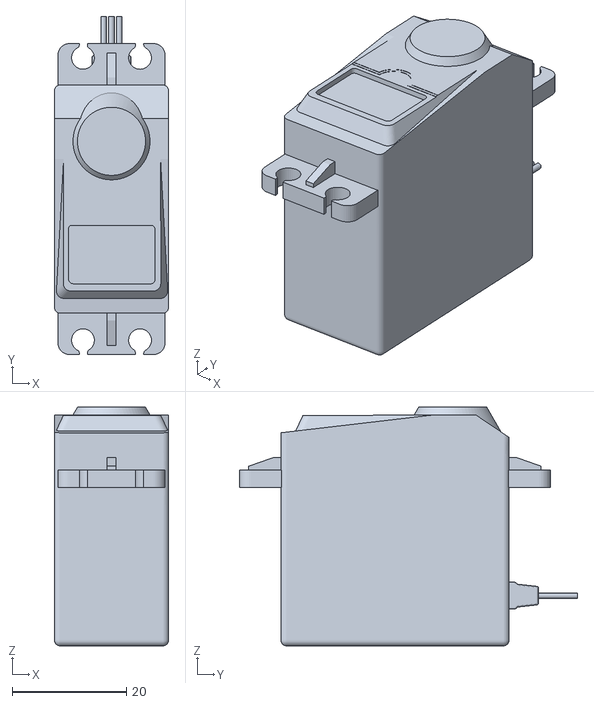
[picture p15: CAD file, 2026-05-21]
code/simulation/generated/exported_meshes/servo.stl
20.0 x 59.2 x 41.8

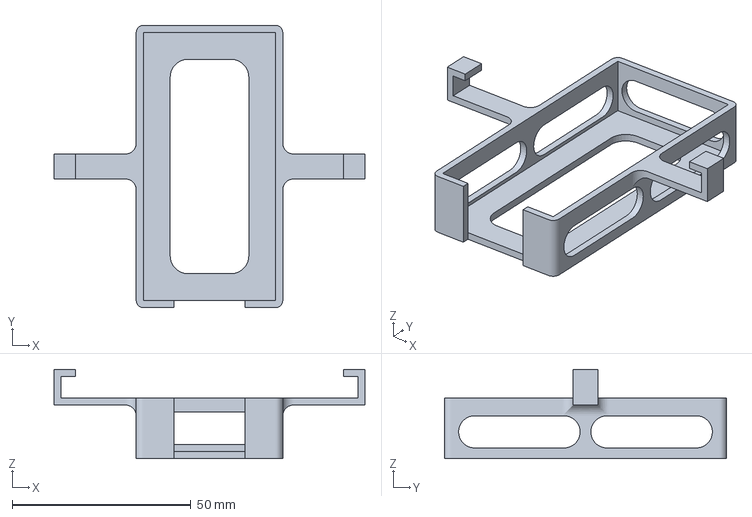
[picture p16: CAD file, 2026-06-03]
cad/body/prusa/LipoCagePrint.3mf
87.0 x 79.0 x 25.0 mm

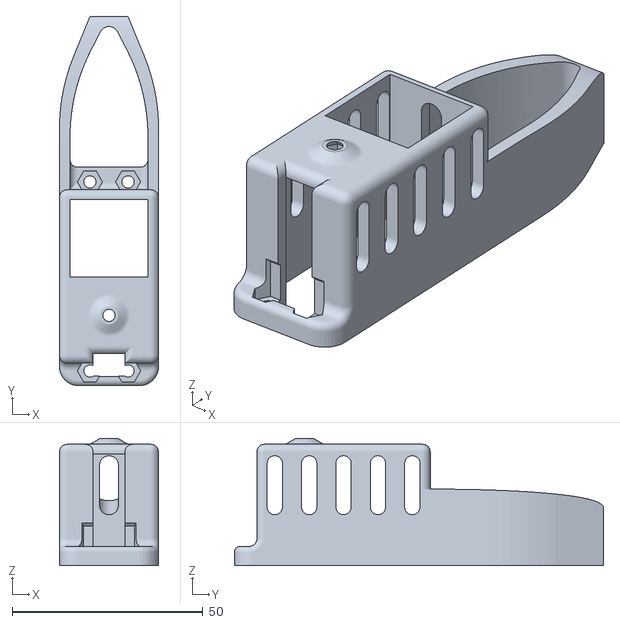
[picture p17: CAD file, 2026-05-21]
cad/leg/Link3.stl
26.0 x 96.7 x 33.3

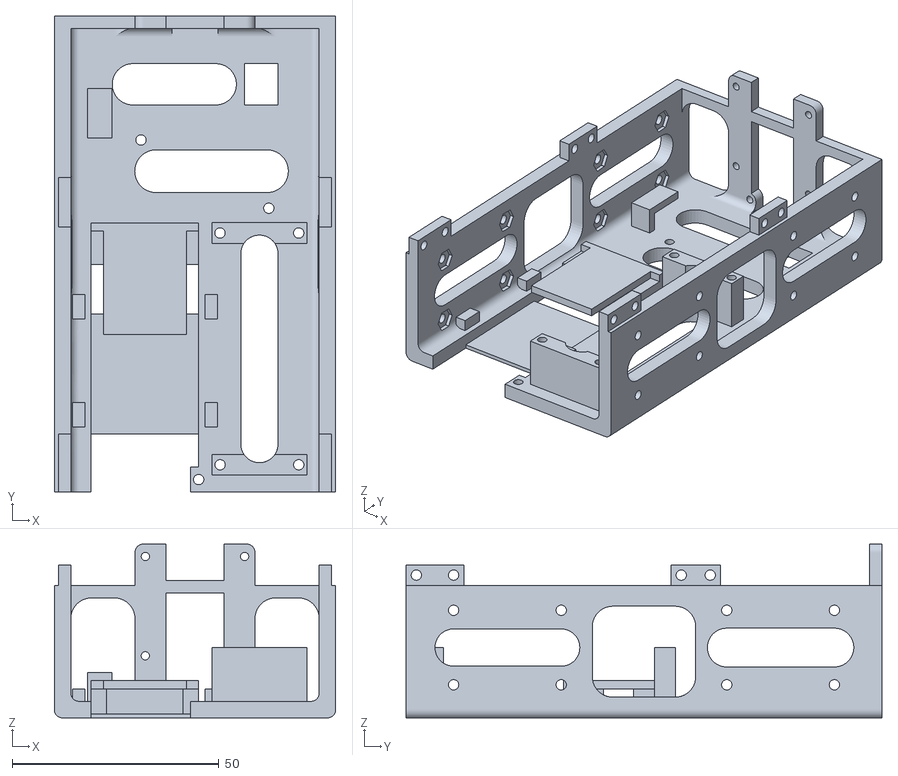
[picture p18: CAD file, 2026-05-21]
cad/body/QuadrupedBody.stl
68.0 x 115.0 x 42.0

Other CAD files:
code/simulation/generated/exported_meshes/leg_shoulder_R.stl
cad/leg/Link1R.stl
cad/body/Shell.stl
code/simulation/generated/exported_meshes/leg_lower.stl
animation/fh_rigged_latest.blend
cad/body/LipoCage.stl
code/simulation/generated/exported_meshes/leg_mount_L.stl
code/simulation/generated/exported_meshes/leg_mount_R.stl
code/simulation/generated/exported_meshes/leg_shoulder_L.stl
code/simulation/generated/exported_meshes/leg_upper.stl

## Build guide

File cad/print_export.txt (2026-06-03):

# FaceHugger — printable-STL export spec
#
# One body per line. The ExportPrintableSTLs Fusion script reads this file,
# finds each body in the currently-open assembly, and writes a binary STL at
# Fusion's HIGH mesh refinement to cad/<subfolder>/<body_name>.stl.
#
# Format:
#     <subfolder>    <body_name>    [up_axis]    [hint]
#
# Required:
#   - subfolder : "body" or "leg". The script creates cad/<subfolder>/ if missing.
#   - body_name : name of the BRep body inside the assembly (case-sensitive).
#
# Optional (any order after body_name — classified by token shape):
#   - up_axis   : one of {+X, -X, +Y, -Y, +Z, -Z}. The body's named local axis
#                 is rotated to point along the slicer's +Z (up). Rotation is
#                 baked into the STL so the part loads pre-oriented in the
#                 slicer. Default = +Z (no rotation).
#   - hint      : substring matched against the occurrence path. Only needed
#                 when the same body name appears in multiple components.
#                 Plain word, or write `hint=<value>` explicitly.
#
# Examples:
#     body   QuadrupedBody
#     body   QuadrupedBody    +Y                     # +Y body axis is print-up
#     leg    Link2            -Z                     # upside down
#     leg    Link2            hint=Link2L:1          # disambiguate
#     leg    Link2            +Y  Link2L:1           # both axis and hint
#
# Lines starting with # are comments. Blank lines are ignored.
# Run from Fusion via:  Shift+S → Scripts and Add-Ins → ExportPrintableSTLs → Run.
# Open the full assembly (with chassis + legs as xrefs loaded) before running.

# --- Chassis bodies (cad/body/) ---
body   QuadrupedBody
body   MiddleBridge
body   BehindBridge
body   LipoCage

# --- Leg-assembly bodies (cad/leg/) ---
# leg    LegMountL     +X
# leg    LegMountR     +X
leg    Link1L        -X
leg    Link1R       -X
leg    Link2        +Z
leg    Link3        -X

# === EXPORT LOG (auto-managed below — do not edit) ===

# Last export : 2026-06-01 14:04:17 CEST
# Source doc  : FullBodyAssembly
# Refinement  : MeshRefinementHigh (binary STL, design units)
# Exported    : 10 body·ies
#   ✓ body/QuadrupedBody.stl    ← FlexibleSkeleton:1/QuadrupedBody:1
#   ✓ body/MiddleBridge.stl    ← FlexibleSkeleton:1/QuadrupedBody:1
#   ✓ body/BehindBridge.stl    ← FlexibleSkeleton:1/QuadrupedBody:1
#   ✓ body/LipoCage.stl    ← FlexibleSkeleton:1/LipoCage:1
#   ✓ leg/LegMountL.stl    ← FaceHuggerLegAssembly:1/MotorMount:1  [up=+X]
#   ✓ leg/LegMountR.stl    ← FaceHuggerLegAssembly:1/MotorMountR:1  [up=+X]
#   ✓ leg/Link1L.stl    ← FaceHuggerLegAssembly:1/Link1L:1  [up=-X]
#   ✓ leg/Link1R.stl    ← FaceHuggerLegAssembly:1/Link1R:1  [up=-X]
#   ✓ leg/Link2.stl    ← FaceHuggerLegAssembly:1/Link2L:1
#   ✓ leg/Link3.stl    ← FaceHuggerLegAssembly:1/Link3L:1  [up=-X]
# Failures    : 0

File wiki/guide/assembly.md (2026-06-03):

# Assembly

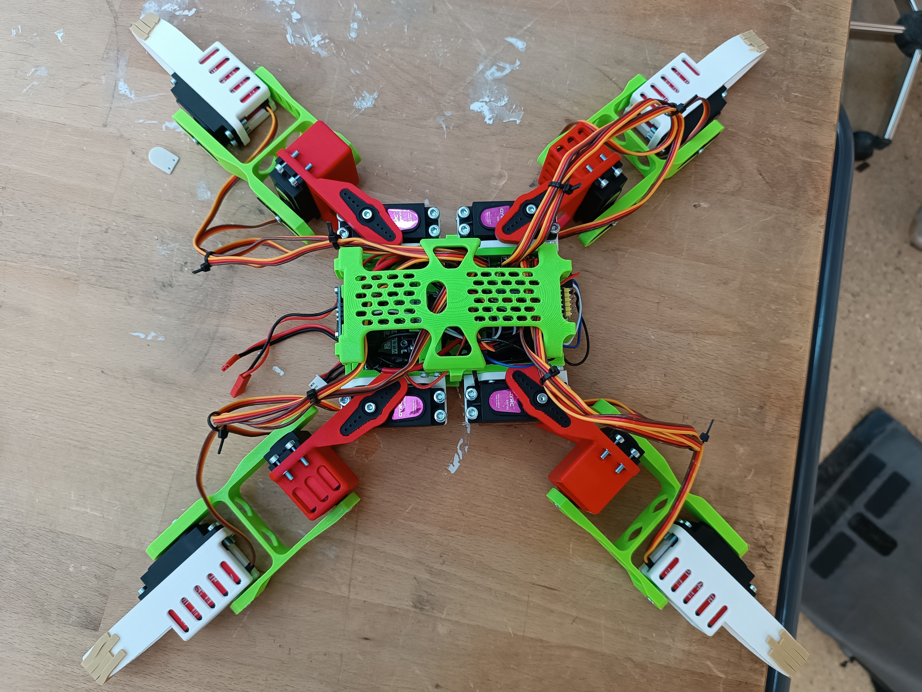
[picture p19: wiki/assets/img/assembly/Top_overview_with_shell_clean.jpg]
FaceHugger completed robot, top view with shell


This guide walks you through building the FaceHugger from scratch. It is written for a complete beginner: every step explains not just *what* to do but *why*, and what to watch out for. Read each step fully before acting on it.

**Estimated time:** 4 to 6 hours for a first build.

**Colour guide for printed parts:** In the photos, the body and mounts are **green**, the thighs and hips are **red**, and the knees are **white**. Link 2 and Link 3 are **green**. This makes it easier to identify parts in the pictures.

## Before you start

!!! note "Checklist: verify everything before beginning"

    Do not skip this step. Discovering a missing part mid-build is very frustrating.

    **Printed parts**

    | Part | Qty | Colour in photos |
    |---|---|---|
    | Shell (body top cover) | 1 | Green |
    | Body frame | 1 | Green |
    | Mounts (leg attachment brackets) | 4 | White |
    | LiPo cage (battery holder) | 1 | Green |
    | Rubber pad for LiPo | 1 | Beige/tan |
    | Link 1 (Hip) | 4 | Red |
    | Link 2 (Thigh) | 4 | Green |
    | Link 3 (Knee housing) | 4 | White |

    **Hardware / fasteners**

    !!! tip "Tip: sort your screws first"
        Before starting, separate all screws and nuts into labelled groups (a muffin tin or small cups work well). Nothing slows a build down more than hunting for the right M3 screw.

    | Location | Fastener | Qty |
    |---|---|---|
    | Mounts → Body | M2.5×8 screws | 16 |
    | Mounts → Body | M2.5 hex nuts | 16 |
    | Hip servo | M4×12 screws | 12 |
    | Hip servo horn | M3×8 screws | 4 |
    | Hip hex nuts | M4 hex nuts | 12 |
    | Hip servo horn hex nut | M3 hex nuts | 4 |
    | Thigh servo | M3×12 screws | 16 |
    | Thigh ball bearing + servo horn | M3×8 screws | 8 |
    | Thigh hex nuts | M3 hex nuts | 20 |
    | Knee servo | M3×12 screws | 16 |
    | Knee ball bearing + servo horn | M3×8 screws | 8 |
    | Knee hex nuts | M3 hex nuts | 20 |
    | Bridges | M2.5×6 screws | 7 |
    | OLED screen | M2×10 screws | 4 |
    | OLED screen | M2 hex nuts | 4 |
    | ESP32 | M2.5×5 screw | 1 |
    | ToF sensors (×3) | M2×4 screws | 6 |
    | IMU | M2.5×2 screws | 2 |
    | PCA9685 Multiplexer | M2.5×6 screws | 4 |
    | Buck Converter | M2.5×5 screws | 2 |
    | Servo horns (all legs) | M3×8 screws | 12 |

    **Electronics**

    | Component | Qty | Notes |
    |---|---|---|
    | QYRC DS-3230MG servo | 12 | 3 per leg |
    | PCA9685 PWM multiplexer | 1 | The servo controller board |
    | ESP32 | 1 | The main microcontroller |
    | OLED screen (0.96" I²C) | 1 | |
    | IMU (MPU-6050) | 1 | The gyroscope/accelerometer |
    | ToF distance sensors | 3 | Time-of-Flight sensors |
    | BMS (Battery Management System) | 1 | Protects the LiPo |
    | Buck Converter | 1 | Steps voltage down to 5V |
    | Capacitor | 1 | For power smoothing |
    | LiPo 2S battery | 1 | Handle carefully (see battery warnings) |
    | Ball bearings | 12 | 3 per leg (1 knee + 1 thigh + 1 hip side) |
    | Servo horns | 12 | Usually included with servos |
    | Elastic bands | 4 | One per leg knee |
    | Zip ties | 4 | For cable management |
    | FF jumper cables | 2 | Female-to-Female, for capacitor |
    | I²C cable trees | 4 | 1-female → 3-female splitters: VCC, GND, SDA, SCL |

    **Tools you will need**

    - Soldering iron + solder
    - Wire strippers
    - Small Phillips-head screwdriver
    - Hex/Allen key set (M2, M2.5, M3, M4)
    - Tweezers or needle-nose pliers (for inserting hex nuts)
    - Multimeter (recommended, for checking solder joints)

## Overview of the build

The FaceHugger has three major sections built in this order:

1. **Legs**: Build all four legs first, completely, before touching the body. The four legs are built the same way; they differ only in the left/right variant of Link 1 and the leg/hip mount.
2. **Body electronics**: Solder and mount all electronics into the body frame.
3. **Final assembly**: Attach legs to body, route all wiring, connect the battery last.

## Part 1: Legs

The robot has four legs: front-left (FL), front-right (FR), back-left (BL), and back-right (BR). They are left/right mirror pairs, not four identical copies: the thigh (Link 2) and knee (Link 3) are the same on every leg, while Link 1 and the leg/hip mount come in a left and a right variant. Each leg consists of three segments connected in a chain:

- **Knee** (white): the foot/lower segment. Contains one servo and one ball bearing.
- **Thigh** (red): the middle segment. Contains one servo and one ball bearing.
- **Hip** (red): the upper segment that connects to the body. Contains one servo.

The segments are connected by printed link pieces:

- **Link 3** (green, H-shaped, labelled "3"): connects knee servo output to thigh.
- **Link 2** (green, H-shaped, labelled "2"): connects thigh servo output to hip.
- **Link 1** (red, large bracket): is the hip itself, which clips onto the body mount.

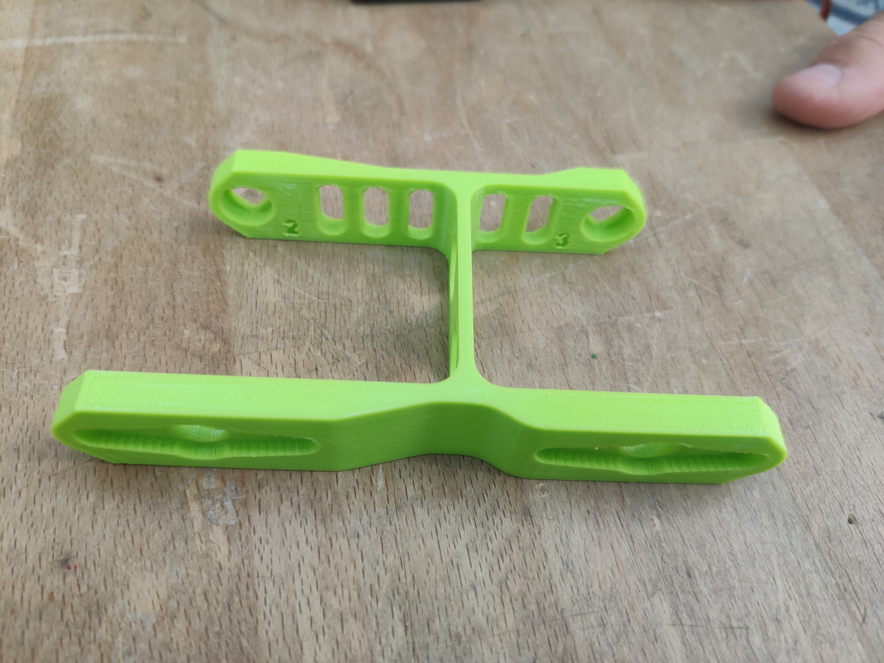
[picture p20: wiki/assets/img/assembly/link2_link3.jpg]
Link 2 (top, green H-piece) and Link 3 (bottom, green paddle) side by side


!!! tip "Identify your link pieces"
    Look closely at the green H-shaped link pieces: they have small numbers ("2" and "3") moulded into them. Make sure you use the right one at each stage. Using the wrong link will result in a leg that can't move correctly.

**Build one complete leg start-to-finish, then repeat ×3.**

### Step 1: Knee, insert hex nuts

Take one **knee piece** (white, elongated shell shape) and locate the hex nut slots. There are **5 slots**: four in a square pattern (for the servo screws) and one on the side (for the ball bearing).

!!! warning "Insert hex nuts BEFORE the servo"
    The hex nuts must go in first, while you have clear access. Once the servo is in, you cannot reach the slots. Push each hex nut firmly into its slot using tweezers or the tip of a screwdriver. They should sit flush. If a nut spins when you later try to drive a screw into it, it was not seated properly.

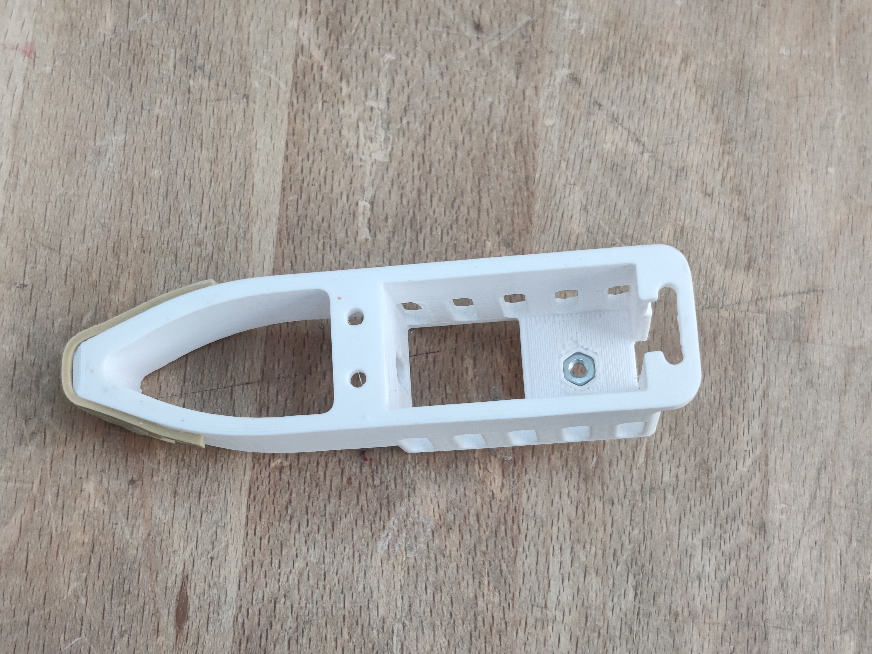
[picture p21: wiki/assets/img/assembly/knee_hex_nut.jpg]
Knee piece with one M3 hex nut inserted into the side slot


**Fasteners for this step:** 5× M3 hex nuts.

### Step 2: Knee, install the servo

Take one **DS-3230MG servo**. Before inserting it, notice the cable: it needs to come out through the **small rectangular hole** on the side of the knee piece, not just hang loose.

Insert the servo into the opening in the knee. The servo body should sit flush inside the housing. Thread the cable through the exit hole as you push the servo in.

Secure the servo with **4× M3×12 screws**, one in each corner. Tighten evenly, and do not overtighten, as the printed plastic can crack.

!!! warning "Cable routing"
    Before tightening the screws, confirm the cable exits cleanly through the hole and is not pinched between the servo and the housing wall. A pinched cable will eventually fray and cause signal issues.

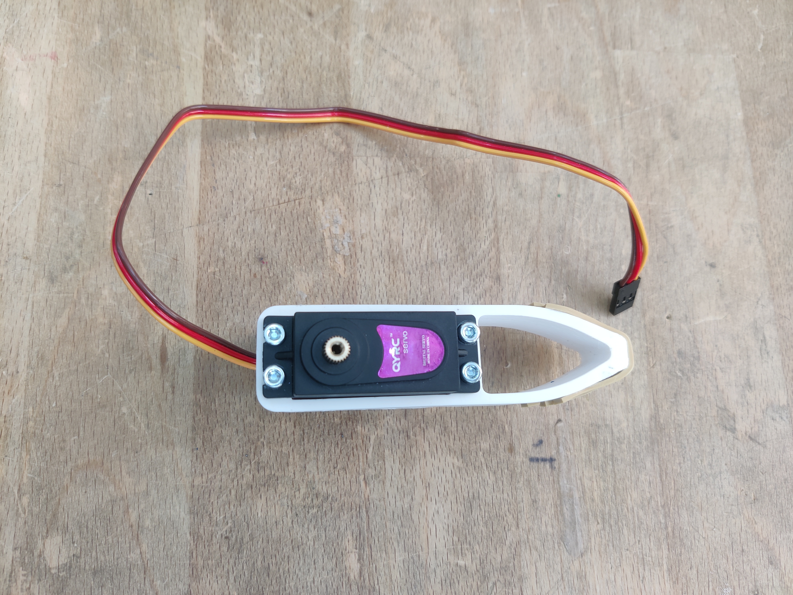
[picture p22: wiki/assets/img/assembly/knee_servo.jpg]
Knee with servo installed, cable routed correctly out of the side hole


**Fasteners for this step:** 4× M3×12 screws.

### Step 3: Knee, install the ball bearing

The ball bearing goes on the **opposite end** from the servo gear (the rounded tip of the knee piece). 

Thread an **M3×8 screw** through the centre of the bearing and into the hex nut you inserted in Step 1. Tighten until snug, but the bearing should spin freely without rattling.

!!! tip "Check bearing spin"
    After tightening, spin the bearing with your finger. It should rotate smoothly with no grinding or wobble. If it grinds, the screw is overtightened, so back off slightly.

!!! warning
    Don't screw the ball bearing too far (hence the use of a M3x8) to not damage the servo.

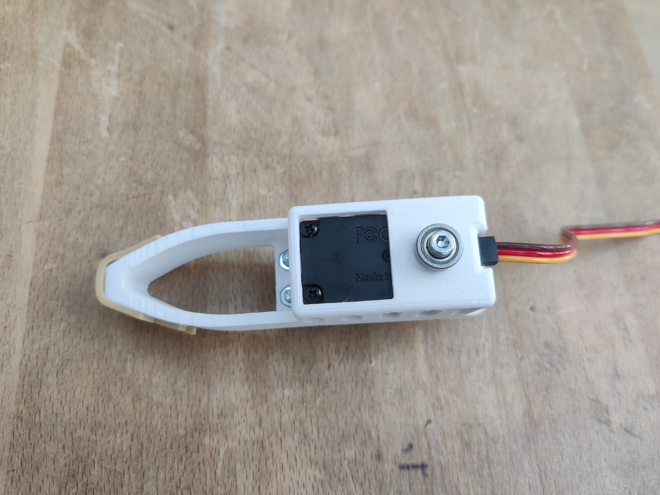
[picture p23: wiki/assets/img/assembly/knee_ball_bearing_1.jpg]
Side view showing ball bearing installed at the tip of the knee, with servo visible behind


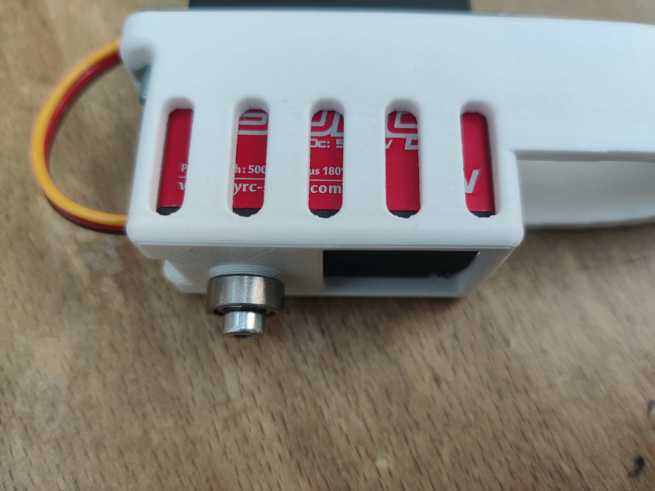
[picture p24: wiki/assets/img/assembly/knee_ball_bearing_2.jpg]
Close-up showing ball bearing seated and screw tightened


**Fasteners for this step:** 1× M3×8 screw.

The knee is now complete.

### Step 4: Add Link 3 to the knee

Take the **Link 3** piece (the green H-shaped piece labelled "3"). One side of the H has two round recesses for a servo horn; the other side has two recesses for a ball bearing pivot.

Insert the **knee assembly** into the ball-bearing side of Link 3 so that the bearing fits into the matching socket in the link. Then take a **servo horn** and press it onto the servo spline (the toothed shaft coming out of the servo). Align it so the arm points in a neutral direction (see image below), then secure with **1× M3×8 screw** through the horn centre into the servo.

!!! tip "Servo horn orientation"
    The servo horn should point roughly perpendicular to the knee piece's long axis when the servo is at its centre position (90°). This gives maximum range of motion in both directions. If you are unsure, centre the servo electronically before attaching the horn.

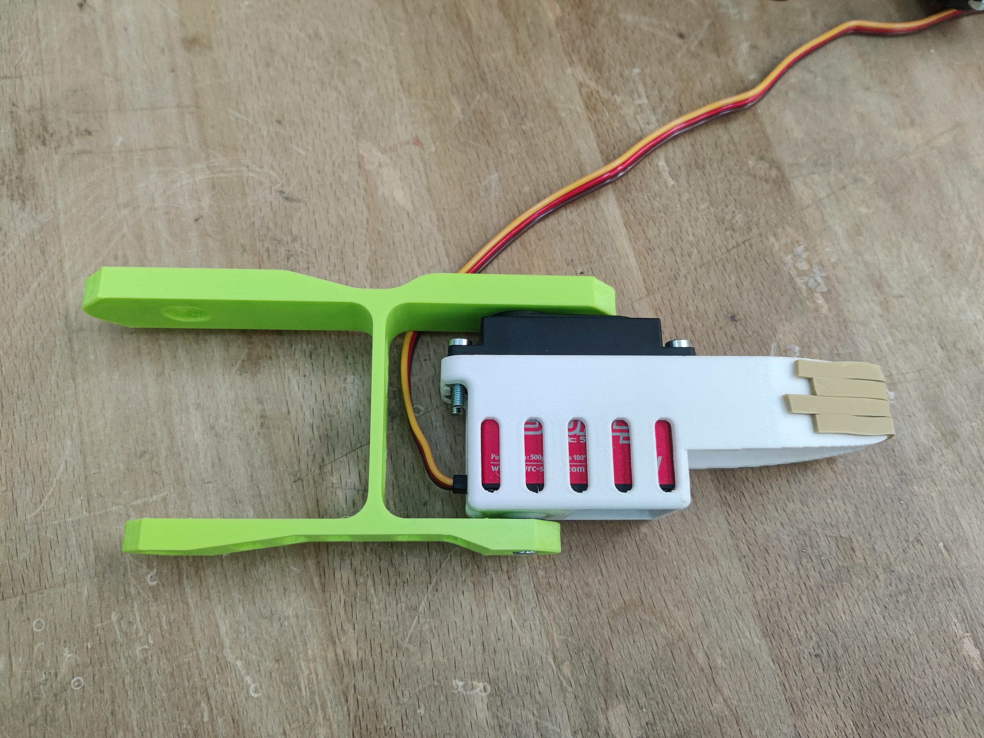
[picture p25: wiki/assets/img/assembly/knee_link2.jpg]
Knee inserted into Link 3, servo horn screwed on


**Fasteners for this step:** 1× M3×8 screw (servo horn).

### Step 5: Thigh, insert hex nuts

Take one **thigh piece** (red, U-shaped bracket). This is a more open structure than the knee. Insert **5× M3 hex nuts** into the slots, four for the servo and one for the ball bearing, following the same approach as Step 1.

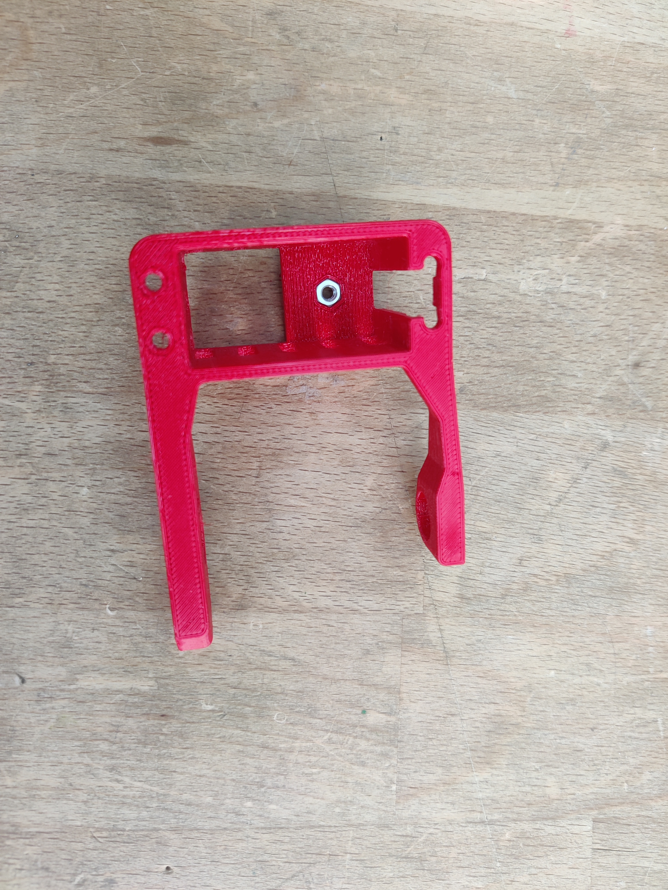
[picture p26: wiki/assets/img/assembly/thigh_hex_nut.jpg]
Thigh piece with hex nut inserted in the servo-side slot


!!! note "Link 2 and Link 3 are the same on every leg"
    All four thighs (Link 2) and knees (Link 3) are identical, so there is nothing to orient per leg here. The only parts that come in a left and a right variant are **Link 1** and the **leg/hip mounts**, and that is where the leg side is indicated. The embossed number on the piece just identifies the part.

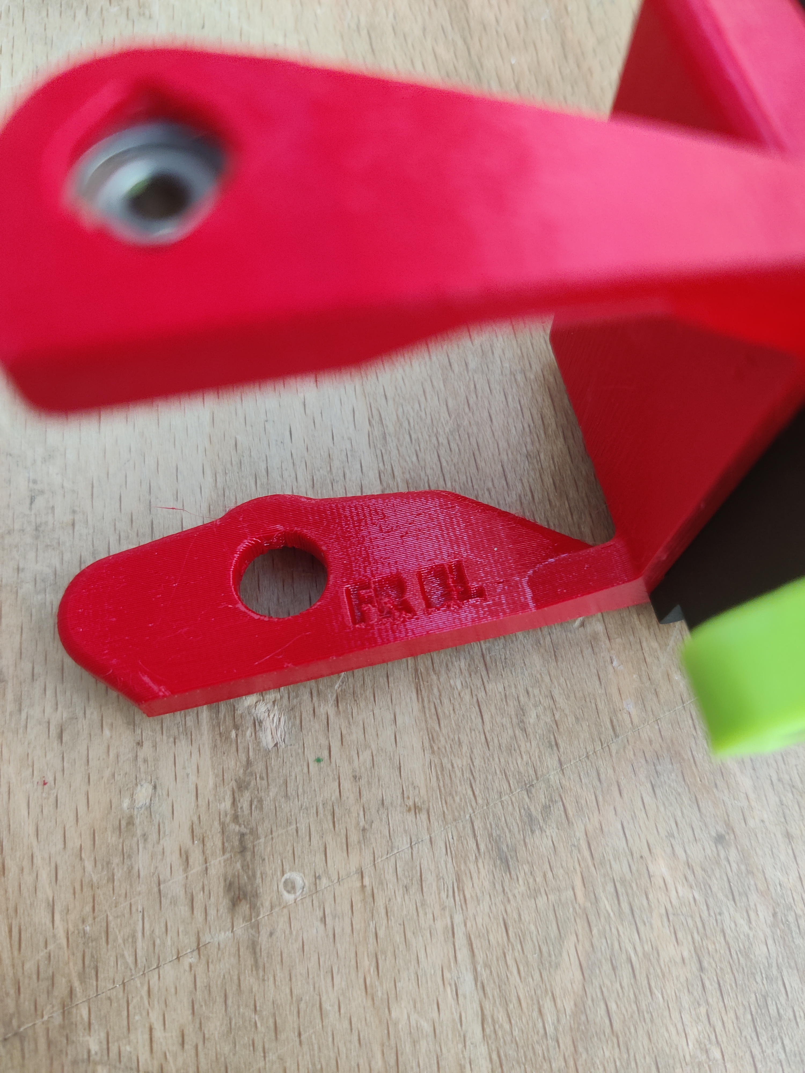
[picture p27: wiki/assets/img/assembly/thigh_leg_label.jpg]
The embossed part number on the Link 2 piece


**Fasteners for this step:** 5× M3 hex nuts.

### Step 6: Thigh, install the servo

Insert the servo into the thigh bracket, cable-first, so the cable exits through the bracket opening. Secure with **4× M3×12 screws**.

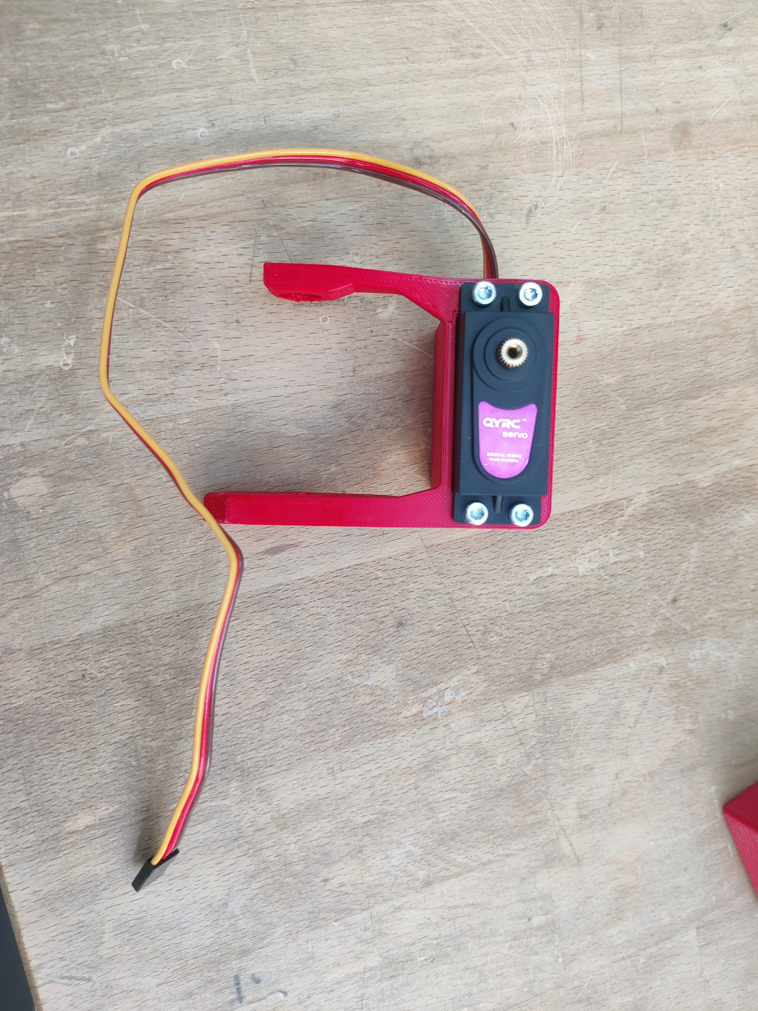
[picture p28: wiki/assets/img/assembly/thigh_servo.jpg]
Thigh with servo installed


**Fasteners for this step:** 4× M3×12 screws.

### Step 7: Thigh, install the ball bearings

Press the ball bearing into the recessed pocket on the free arm of the thigh bracket. Screw another ball bearing on the servo directly with a **M3×8 screw**.

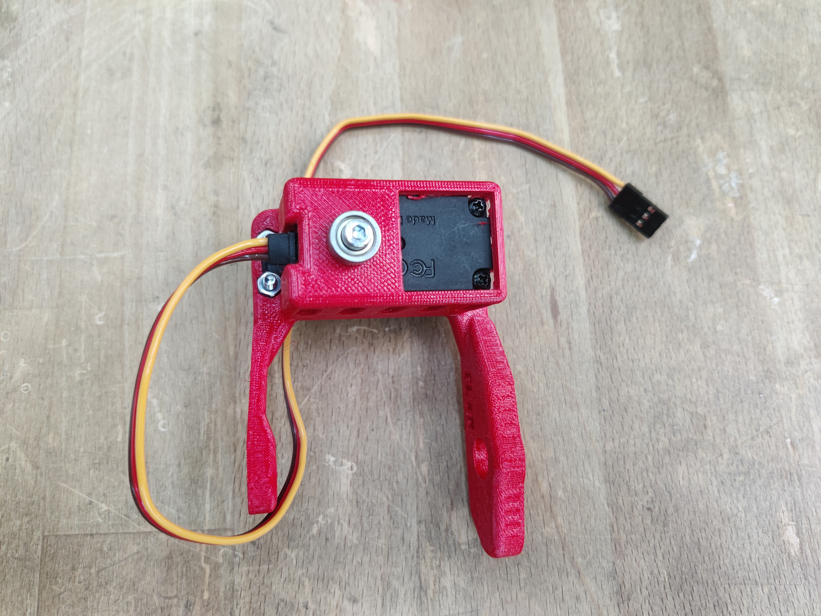
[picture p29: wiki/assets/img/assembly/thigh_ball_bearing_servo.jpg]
Thigh with servo installed and ball bearing fitted on the free arm


**Fasteners for this step:** 1× M3×8 screw.

### Step 8: Add Link 2 to the thigh

Take the **Link 2** piece (green H-shape labelled "2"). Fit the **thigh assembly** into the ball-bearing side of Link 2. Attach the **servo horn** to the thigh servo and screw it to Link 2 with **1× M3×8 screw**.

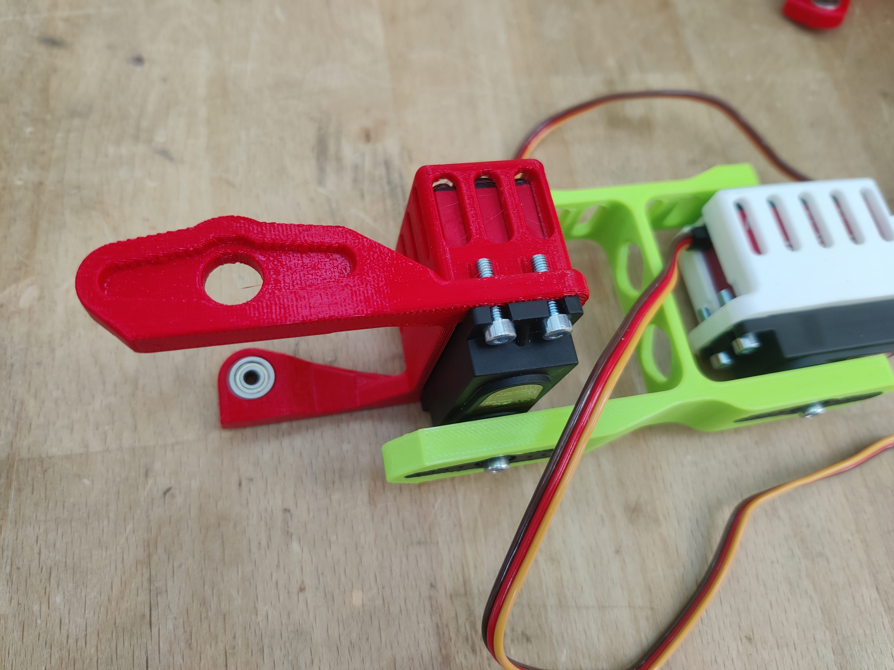
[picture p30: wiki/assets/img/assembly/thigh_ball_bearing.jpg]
Alternate angle showing thigh, ball bearing, and the knee assembly nearby


**Fasteners for this step:** 1× M3×8 screw (servo horn).

### Step 9: Knee + Thigh sub-assembly check

At this point you should have the knee (with Link 3) and the thigh (with Link 2) as two separate sub-assemblies. They connect together in the next section.

The knee servo horn on Link 3 mates with the open side of Link 2, the H-piece on the thigh side. Clip the knee's Link 3 into the thigh's Link 2 bracket. This joint should pivot freely around the ball bearing axis.

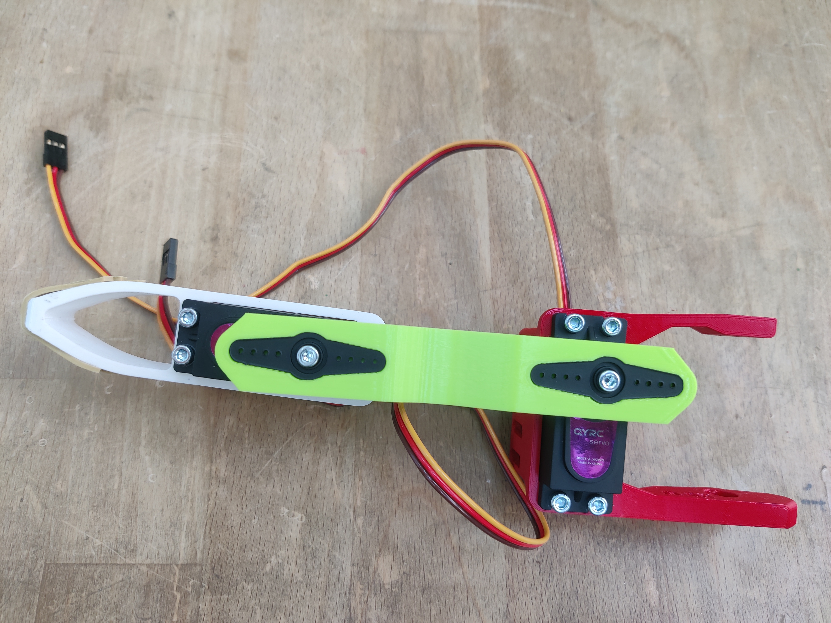
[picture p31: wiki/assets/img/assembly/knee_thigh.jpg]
Completed knee and thigh joined, Link 2 and Link 3 connected, two servo cables visible


!!! tip "Joint freedom check"
    Flex the knee joint by hand. It should move through a wide arc with light resistance from the servo's internal gears. If it feels stiff or grinds, check that the ball bearing screw is not over-tightened.

### Step 10: Hip, insert hex nuts and install servo

Take one **hip piece** (red, larger bracket). Insert hex nuts: **4× M4 hex nuts** for the servo (the hip uses larger M4 screws because it bears more load) and **1× M3 hex nut** for the servo horn side.

Insert the servo and secure with **4× M4×12 screws**.

**Fasteners for this step:** 4× M4 hex nuts, 1× M3 hex nut, 4× M4×12 screws.

### Step 11: Attach full leg to hip (Link 1)

The hip piece **is** Link 1. Clip the thigh+knee sub-assembly onto the hip by mating the open bracket end of Link 2 with the hip bracket. The hip servo horn connects to Link 2.

Attach the servo horn to the hip servo, ensuring it points in the correct neutral direction. Screw the horn to Link 2 with **1× M3×8 screw**. Screw the ball bearing that's on the bottom side of the mount with another **M3x8 screw**.

!!! warning "Horn orientation matters"
    On all three joints, always attach servo horns with the servo at its electrical centre position (command a 90° / 1500µs pulse if using a servo tester). If you attach the horn with the servo off-centre, the leg will have uneven range of motion and may bind at one extreme.

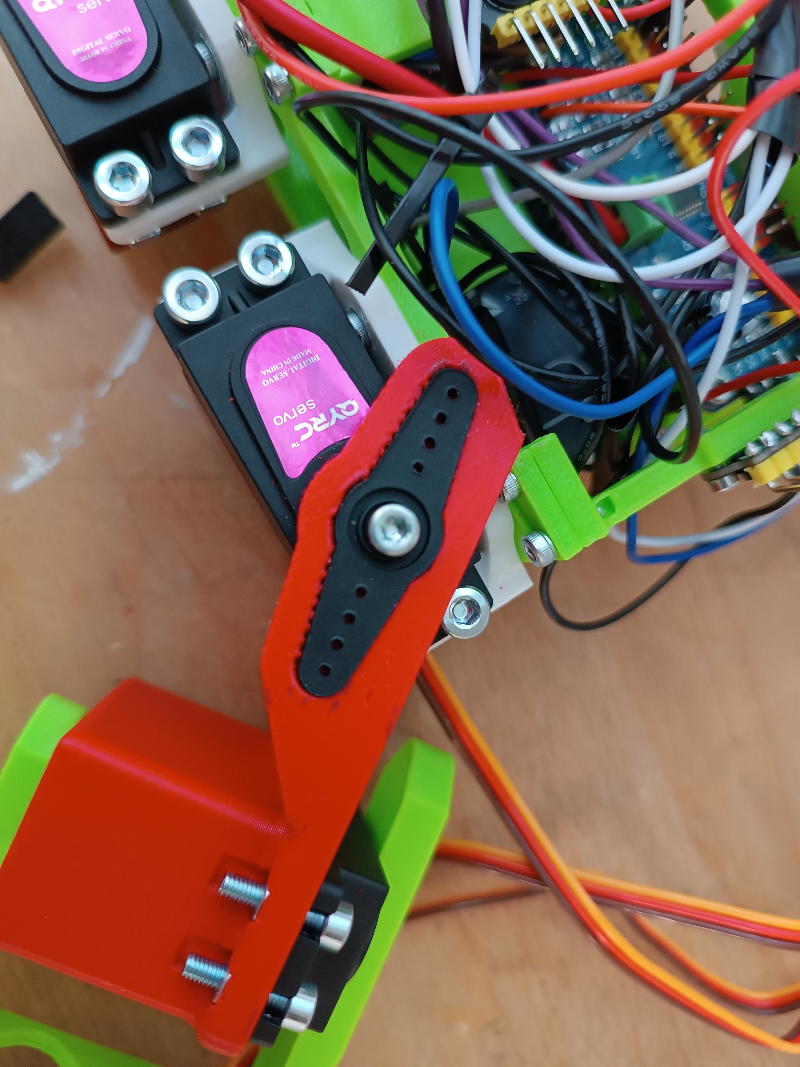
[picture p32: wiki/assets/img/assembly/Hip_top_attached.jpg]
Hip servo with Link 1 arm and servo horn attached, body electronics visible in background


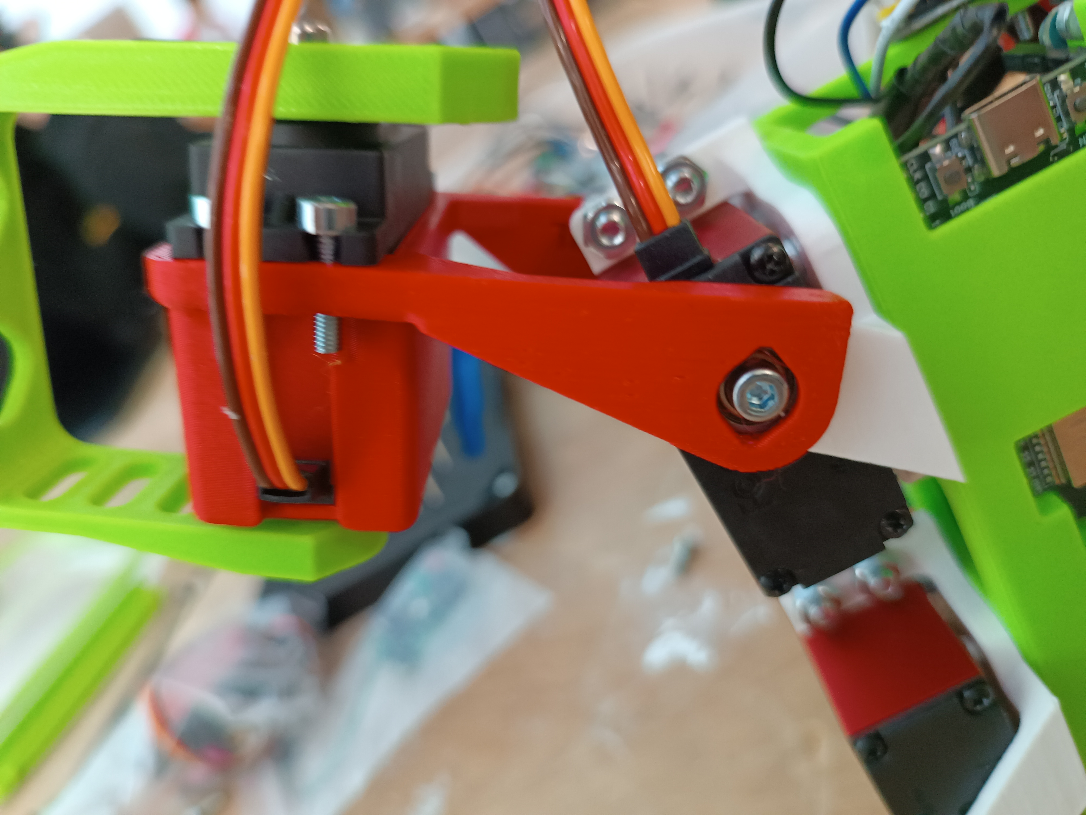
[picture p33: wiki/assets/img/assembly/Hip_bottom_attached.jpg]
Hip from the underside showing servo horn engagement and cable management


**Fasteners for this step:** 2× M3×8 screw.

### Step 12: Elastic band on knee

Fit one **elastic band** around the knee joint area. This provides light return tension and helps keep cable slack from flopping around.

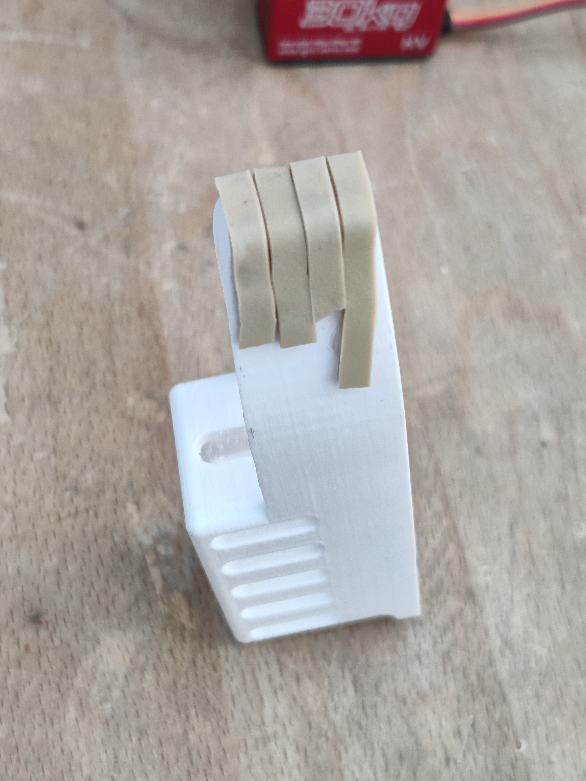
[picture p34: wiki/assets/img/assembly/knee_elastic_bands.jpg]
Knee joint with elastic band fitted


### Repeat Steps 1 to 12 for the remaining three legs

You should now have **four complete leg assemblies**, each with three servos, two ball bearings, and all link pieces attached.

## Part 2: Body electronics

!!! danger "No power during assembly"
    Do not connect the battery at any point during this section. Connect it only as the very last step of the entire build.

### Understanding the electronics

Before soldering, it helps to understand what each board does:

- **ESP32**: The brain. Runs your firmware and controls everything over I²C and PWM.
- **PCA9685 (Multiplexer)**: A 16-channel PWM driver. The ESP32 sends it commands over I²C, and it generates the individual PWM signals for each of the 12 servos.
- **BMS (Battery Management System)**: Protects the LiPo from overcharge, over-discharge, and short circuits. Always sits between the battery and the rest of the electronics.
- **Buck Converter**: Takes the 2S LiPo voltage (~7.4V) and steps it down to a stable 5V for the logic boards. The servos run directly from the LiPo voltage via the PCA9685 power rail.
- **Capacitor**: Smooths voltage spikes when servos draw sudden current. Wired in parallel with the PCA9685's onboard capacitor.
- **IMU (MPU-6050)**: Measures orientation and acceleration. Used by the firmware for balance control.
- **OLED screen**: Small display for status readout.
- **ToF sensors**: Measure distance to objects. Used for obstacle detection.

[Read more about the parts in the Parts & Materials section](parts.md)

### Step 13: Solder the power chain

This is the most critical soldering step. Take your time and double-check polarity at every connection before applying heat.

**What to solder:**

1. Solder the **BMS output** to the **Buck Converter VIN** and the **PCA9685 power input**. The BMS protects everything downstream, so it must be first in the chain.
2. Solder **VIN** and **VOUT** cables to the Buck Converter's terminal pads. On the **input side**, scrape back ~5mm of insulation and tin the wire. On the **output side**, crimp or solder a **female JST/Dupont connector** so it can be plugged and unplugged from the ESP32's 5V pin.

!!! danger "Polarity"
    Red = positive (+), Black = negative (−). Getting this backwards will destroy your boards instantly. Before soldering, trace each wire's origin and confirm its polarity with a multimeter if you are unsure.

!!! tip "Soldering tip for beginners"
    Heat the pad, not the solder. Touch your iron to the pad and the wire simultaneously, then bring solder to the joint, not to the iron. A good joint looks shiny and smooth, like a small volcano. A bad joint looks dull and lumpy ("cold joint") and will fail intermittently.

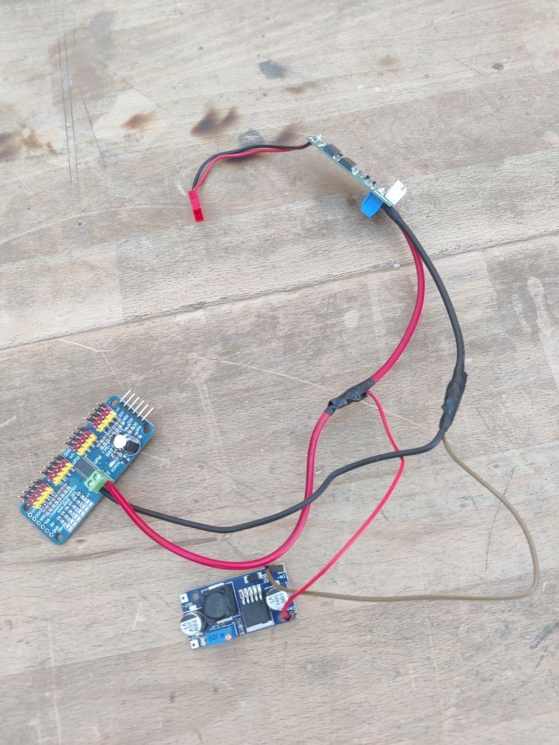
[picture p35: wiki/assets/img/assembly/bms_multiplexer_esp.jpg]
PCA9685 multiplexer, Buck Converter, and BMS with power cables soldered and routed


### Step 14: Capacitor wiring

The capacitor is wired **in parallel** with the PCA9685's built-in capacitor to increase the total energy reserve for servo current spikes.

Using **2× FF jumper cables**, connect:
- One cable: capacitor **+** pin → PCA9685 **V+** power pin
- Other cable: capacitor **−** pin → PCA9685 **GND** power pin

Check that the capacitor's polarity stripe (the light-coloured stripe with minus signs) is on the **−** side.

### Step 15: Prepare the body for electronics

Before inserting any electronics, insert the hex nuts into the body frame.

The body has dedicated mounting holes for the ESP32, PCA9685, Buck Converter, and mounts. Each hole has a slot behind it for a hex nut. Using tweezers, press the appropriate hex nuts into each slot:

- **ESP32:** 1× M2.5 hex nut
- **PCA9685:** 4× M2.5 hex nuts
- **Buck Converter:** 2× M2.5 hex nuts

Now screw the **four white mounts** onto the body's corner attachment points using **4× M2.5×8 screws + M2.5 hex nuts per mount (16 total)**. The mounts are what the legs will clip onto.

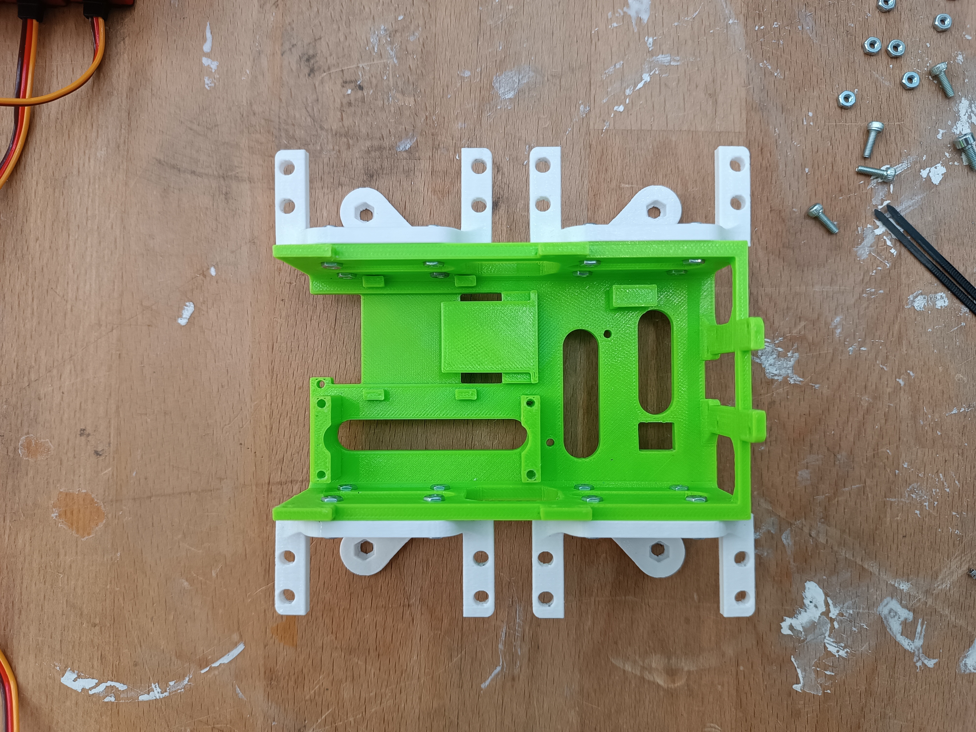
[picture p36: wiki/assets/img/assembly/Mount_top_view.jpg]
Body with all four mounts screwed on, top view, also shows hex nuts seated in the inner slots


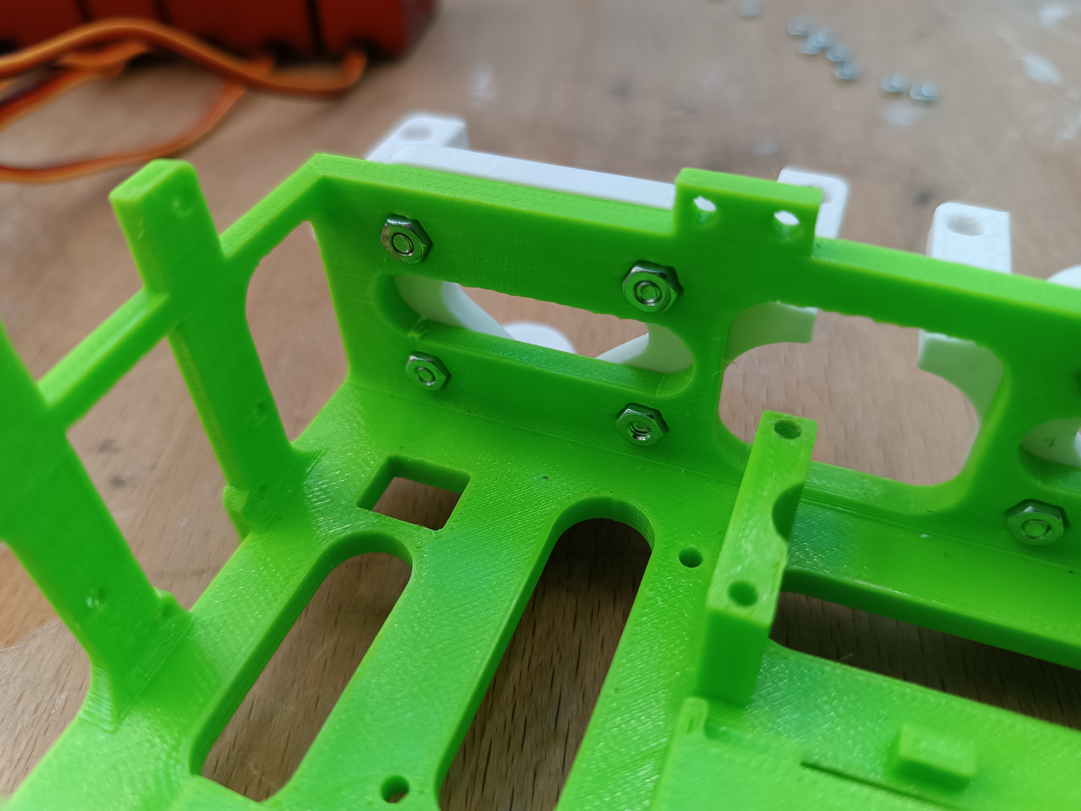
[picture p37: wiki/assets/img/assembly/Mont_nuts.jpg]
Close-up showing hex nuts properly seated into the body's inner slots


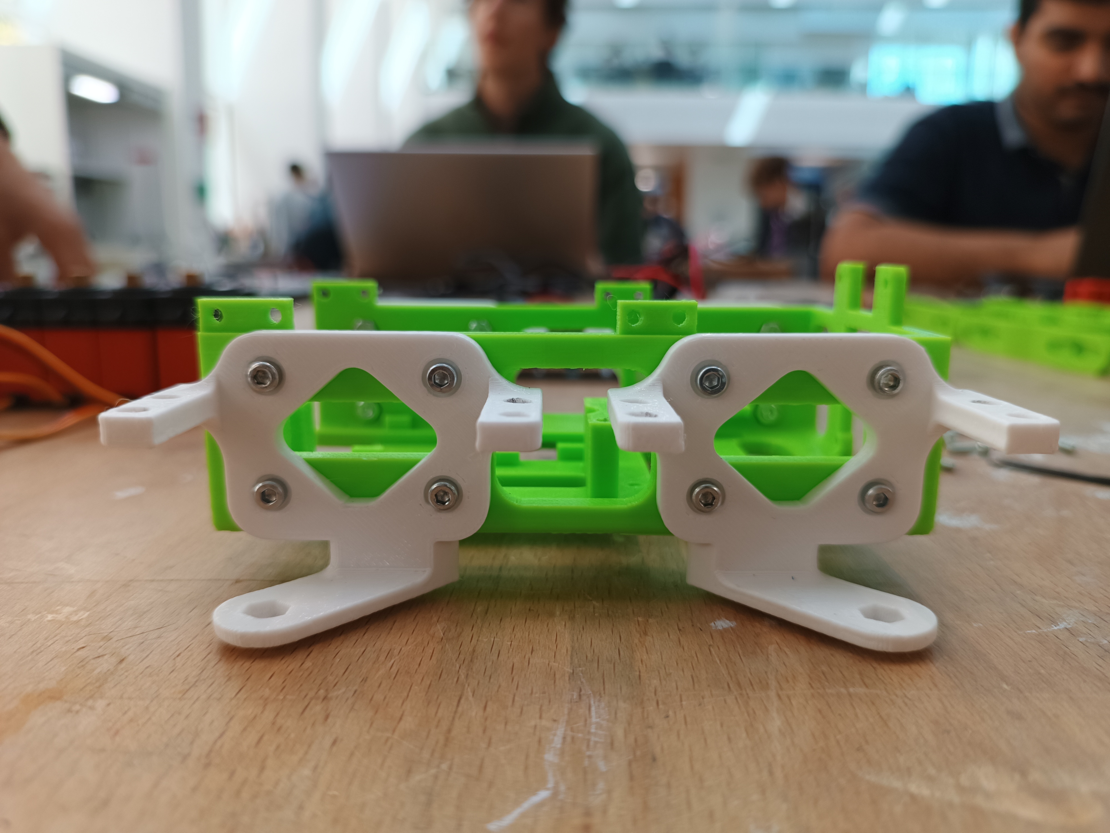
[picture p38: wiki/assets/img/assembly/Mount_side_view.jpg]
Mount from the side, showing the leg attachment tab


### Step 16: Install the ESP32

Slide the **ESP32** into its dedicated slot in the body frame. The USB-C port should face outward so you can still flash firmware after assembly.

Secure with **1× M2.5×5 screw**.

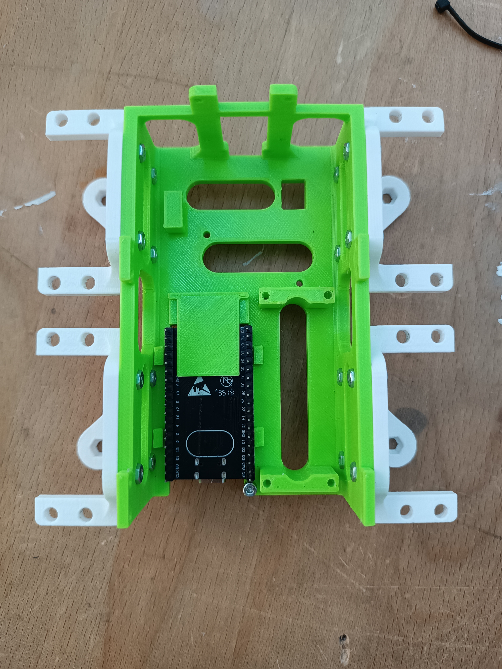
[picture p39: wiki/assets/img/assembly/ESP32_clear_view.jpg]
ESP32 slid into the body slot, USB-C port visible at the front edge


**Fasteners for this step:** 1× M2.5×5 screw.

### Step 17: Install the PCA9685 and Buck Converter

Place the **PCA9685** into its position in the body and screw down with **4× M2.5×6 screws**. The servo output headers should face outward or toward the leg cables.

Place the **Buck Converter** into its position and screw down with **2× M2.5×5 screws**.

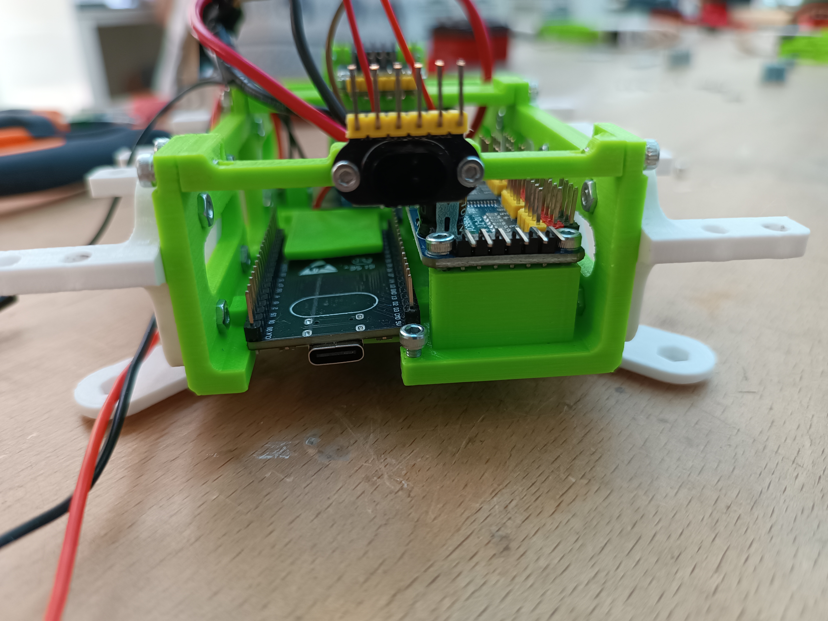
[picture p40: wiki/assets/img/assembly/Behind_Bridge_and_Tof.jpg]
Body from behind showing ESP32 (left), PCA9685 (right) and IMU mounted, cables beginning to be routed


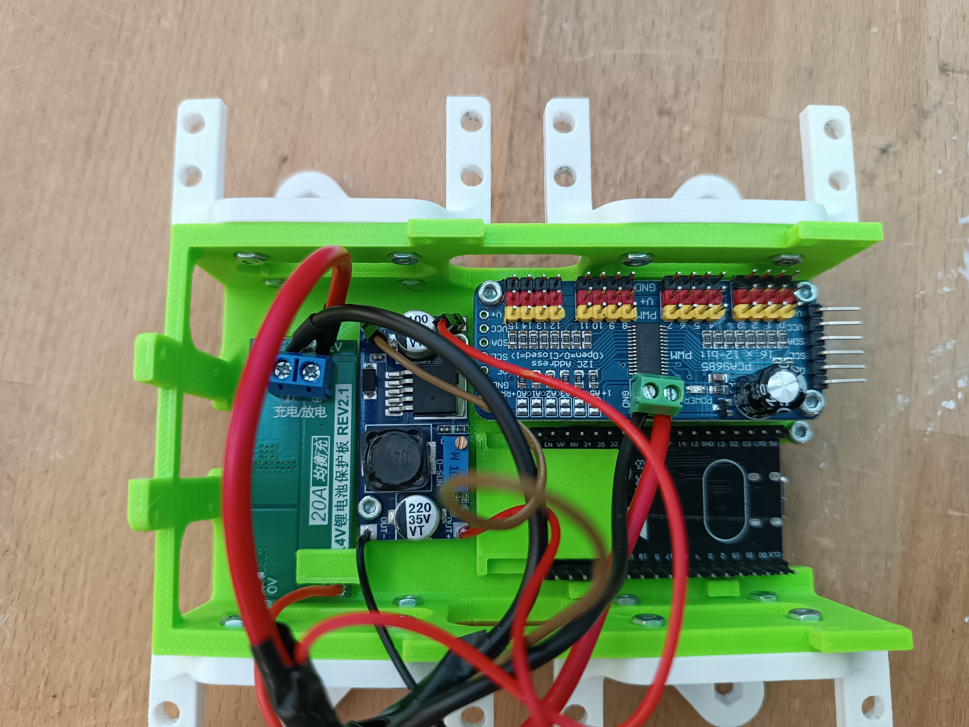
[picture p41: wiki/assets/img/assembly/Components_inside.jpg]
Full top-down view of all electronics boards installed inside the body


### Step 18: Install the bridge, IMU, and OLED

The **bridge** is a small cross-shaped printed piece that mounts on the front face of the body. It holds the **IMU** on one arm and a **ToF sensor** in the centre.

1. Screw the **IMU** onto the bridge arm using **2× M2.5×2 screws**.
2. Screw the **front ToF sensor** onto the bridge centre using **2× M2×4 screws**.
3. Screw the bridge assembly onto the body using **M2.5×6 screws**.

Then mount the **OLED screen** above the front face using **4× M2×10 screws + 4× M2 hex nuts**.

The remaining **2 ToF sensors** mount on the side bridges using **2× M2×4 screws** each.

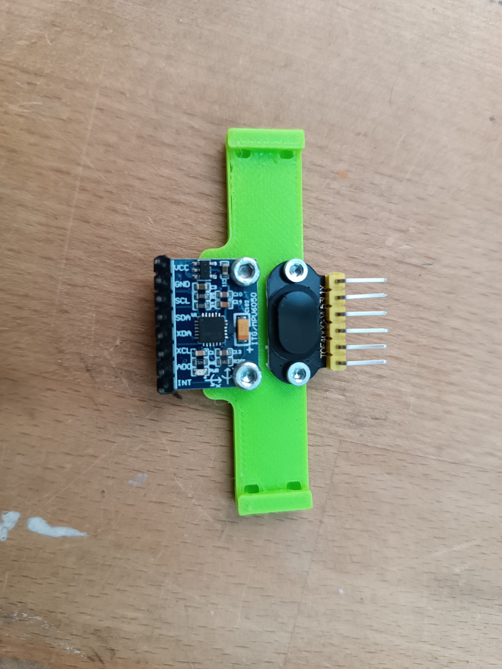
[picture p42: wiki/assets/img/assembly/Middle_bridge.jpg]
Middle bridge with IMU (left, blue board) and ToF sensor (right, black dome) mounted on it before attaching to body


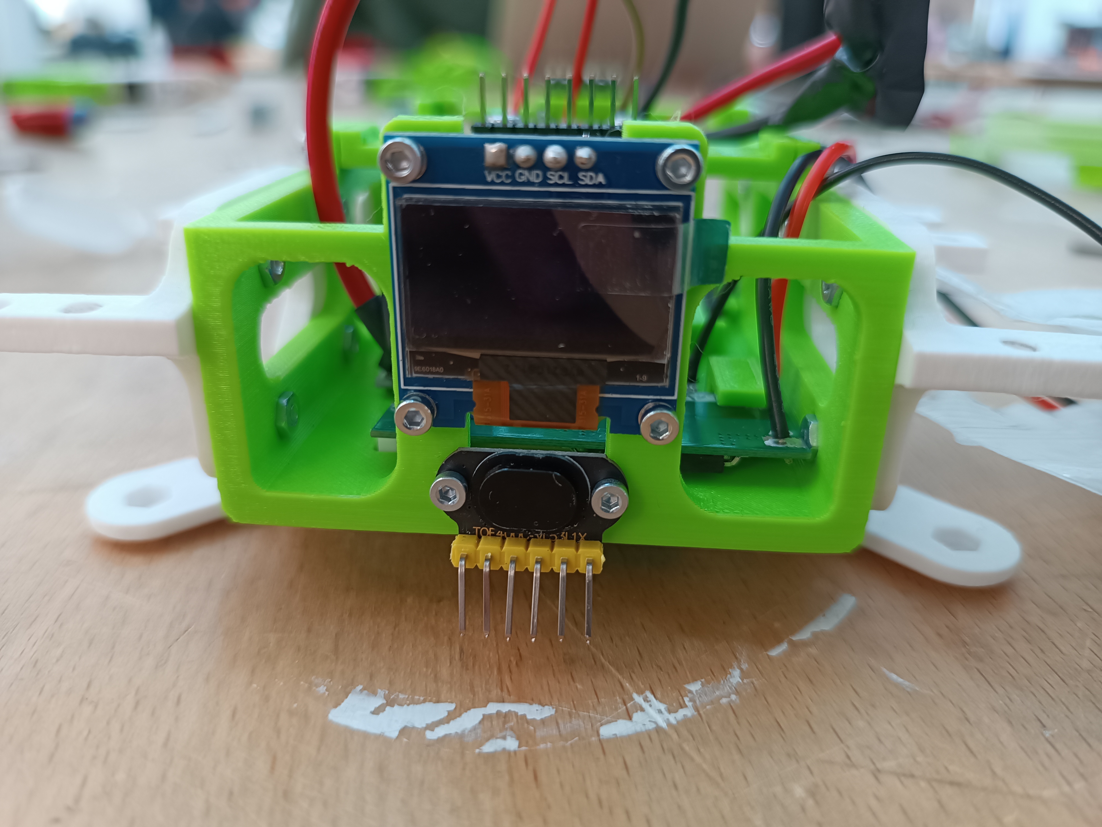
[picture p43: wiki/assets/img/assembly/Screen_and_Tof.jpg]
Front face of the assembled body showing OLED screen (top) and front ToF sensor (bottom)


**Fasteners for this step:** 2× M2.5×2, 2× M2×4 (front ToF), M2.5×6 (bridge), 4× M2×10, 4× M2 hex nuts.

## Part 3: Wiring

!!! warning "Cabling: read before you wire"
    Plan your cable routes before you commit. Cables that cross a moving joint must have enough **slack** to allow the full range of motion without pulling taut. A taut cable will eventually pull off its connector or tear a pad off a PCB. Coil excess length loosely and secure with a zip tie.

### Step 19: I²C cable trees

The ESP32 communicates with the OLED, IMU, and PCA9685 over a single I²C bus (two wires: SDA and SCL, plus power). You need to make **4 cable trees**, one for each signal, so that one ESP32 pin fans out to all three peripherals.

Each cable tree has:

- **1 female connector** on one end → plugs into the ESP32
- **3 female connectors** on the other end → one each for OLED, IMU, PCA9685

If you are also connecting the 3 ToF sensors to the I²C bus, make **3 additional trees** (or use 6-way splits instead).

**I²C pin mapping on the ESP32:**

| Signal | ESP32 pin | Wire colour convention |
|---|---|---|
| VCC (3.3V logic) | 3V3 | Red |
| GND | Any GND | Black |
| SDA (data) | GPIO 21 | Blue or White |
| SCL (clock) | GPIO 22 | Yellow or Green |

!!! tip "Labelling helps"
    Use a marker to write the signal name (VCC / GND / SDA / SCL) on a small piece of tape and wrap it around each cable near the ESP32 connector. This makes debugging much easier later.

Connect each peripheral:

| Peripheral | VCC source | Notes |
|---|---|---|
| OLED screen | 3.3V | Check your specific module (some accept 5V) |
| IMU (MPU-6050) | 3.3V | |
| PCA9685 | 3.3V (logic), 5V (V+) | The V+ pin powers servos via Buck Converter, separate from I²C VCC |
| ToF sensors | 3.3V | |

Refer to the wiring diagram in the project documentation for the full schematic.

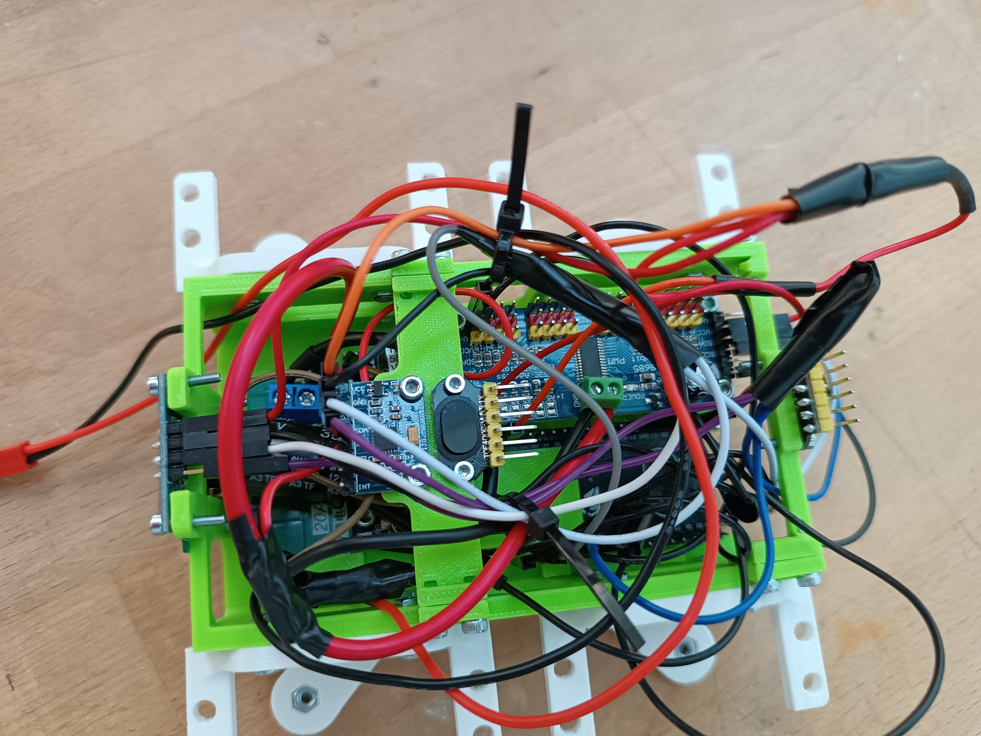
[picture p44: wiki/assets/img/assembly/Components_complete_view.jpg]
Full wired body top-down view showing I²C cables, servo cables, and power cables routed


### Step 20: Connect servo cables to PCA9685

The PCA9685 has 16 servo output channels (0–15). Plug the **12 servo cables** (3-pin JST/Dupont: GND / VCC / Signal) into the exact channels shown below. This mapping must match `config.h`'s `LEG_SERVO_CHANNEL` array — if you ever re-wire a servo to a different channel, update `config.h` to match, or the firmware will drive the wrong servo.

| PCA9685 channel | Leg | Joint | `config.h` constant |
|---|---|---|---|
| 0 | Back-left (BL) | Hip | `BOTTOM_LEFT_LEG_HIP_PCA_CHANNEL` |
| 1 | Back-left (BL) | Thigh | `BOTTOM_LEFT_LEG_THIGH_PCA_CHANNEL` |
| 2 | Back-left (BL) | Knee | `BOTTOM_LEFT_LEG_KNEE_PCA_CHANNEL` |
| 3 | *(unused)* | — | — |
| 4 | Back-right (BR) | Hip | `BOTTOM_RIGHT_LEG_HIP_PCA_CHANNEL` |
| 5 | Back-right (BR) | Thigh | `BOTTOM_RIGHT_LEG_THIGH_PCA_CHANNEL` |
| 6 | Back-right (BR) | Knee | `BOTTOM_RIGHT_LEG_KNEE_PCA_CHANNEL` |
| 7 | *(unused)* | — | — |
| 8 | Front-right (FR) | Hip | `FRONT_RIGHT_LEG_HIP_PCA_CHANNEL` |
| 9 | Front-right (FR) | Thigh | `FRONT_RIGHT_LEG_THIGH_PCA_CHANNEL` |
| 10 | Front-right (FR) | Knee | `FRONT_RIGHT_LEG_KNEE_PCA_CHANNEL` |
| 11 | *(unused)* | — | — |
| 12 | Front-left (FL) | Hip | `FRONT_LEFT_LEG_HIP_PCA_CHANNEL` |
| 13 | Front-left (FL) | Thigh | `FRONT_LEFT_LEG_THIGH_PCA_CHANNEL` |
| 14 | Front-left (FL) | Knee | `FRONT_LEFT_LEG_KNEE_PCA_CHANNEL` |
| 15 | *(unused)* | — | — |

Channels 3, 7, 11, and 15 are intentional gaps — leave them empty. The leg order in `config.h` is 0 = FR, 1 = FL, 2 = BR, 3 = BL.

!!! warning "Plug servo cables the right way"
    The 3-pin servo connector is not keyed, so it can go in backwards. The dark wire (GND) should face the outside edge of the PCA9685 board (the side labelled GND). Check your PCA9685's silkscreen to confirm.

## Part 4: Final assembly

### Step 21: Attach legs to body

Each leg's **hip bracket** clips onto one of the four **white mounts** on the body corners. Slide the hip bracket tabs into the mount slots until they click. No screws are needed for this joint, as it is a friction/clip fit.

Once all four legs are clipped on, confirm each hip can rotate freely by hand.

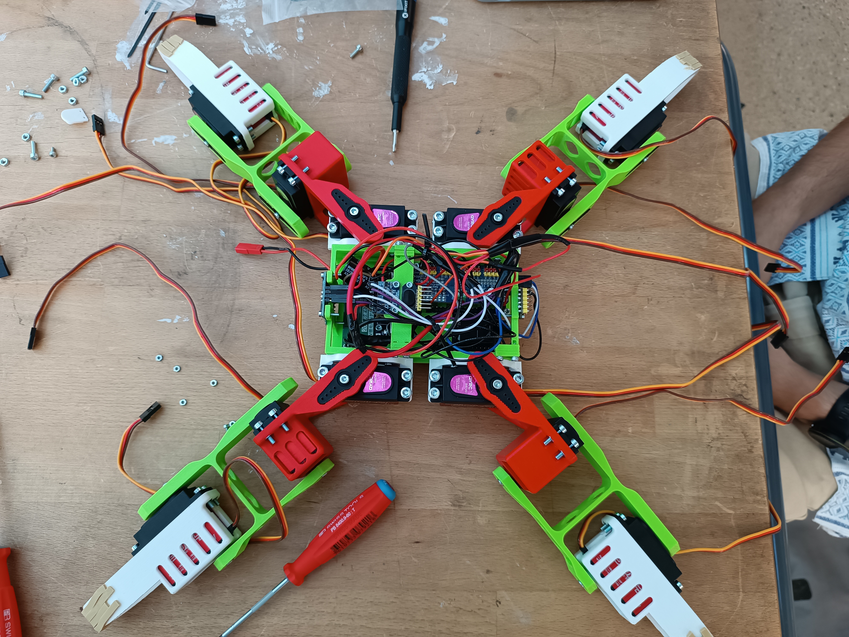
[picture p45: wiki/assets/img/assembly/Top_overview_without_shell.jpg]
Full robot with all four legs attached, no shell, top view


### Step 22: Route and secure all cables

With legs attached, route each servo cable along the leg to the body. Use **zip ties** to bundle cables at the hip joint, leaving a small loop of slack at each joint so movement is unimpeded.

Fold and tuck any excess cable length inside the body cavity. Use the **4 elastic bands** to hold servo cables against the leg structure at the knee joints.

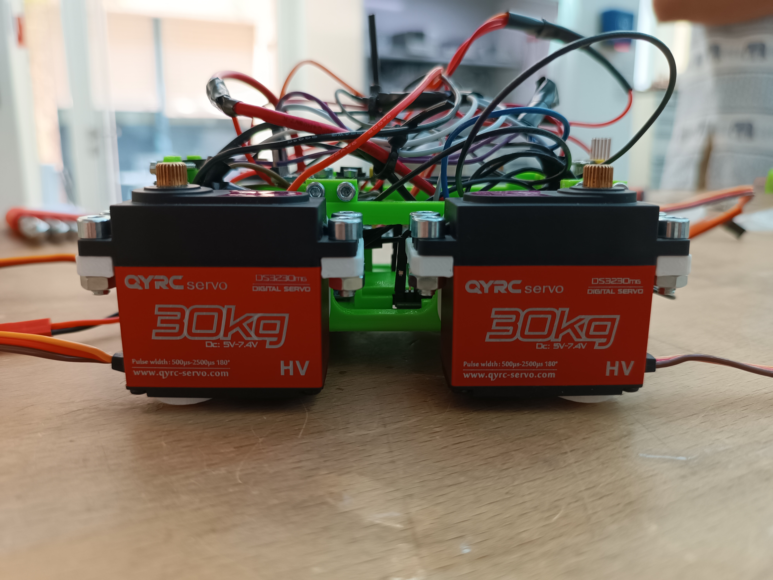
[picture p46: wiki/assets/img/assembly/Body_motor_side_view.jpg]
Body motor side view showing four hip servos and cable routing from legs into body


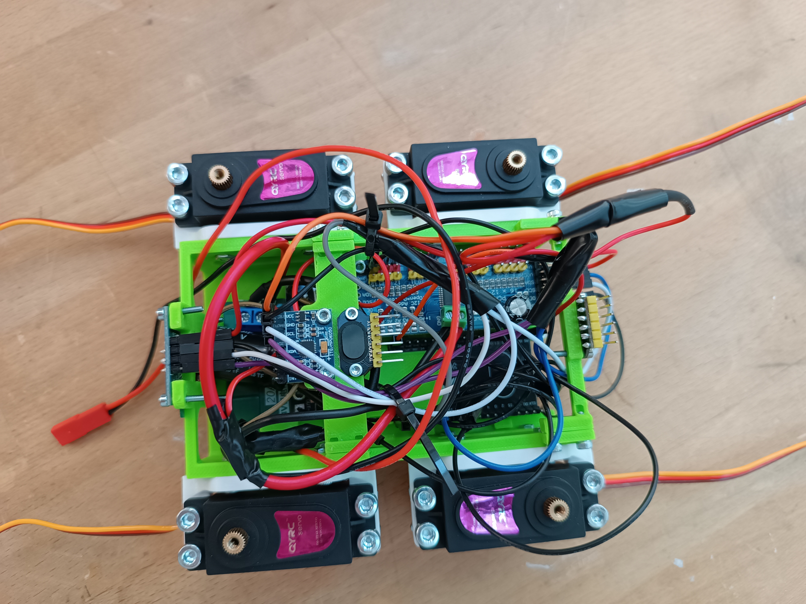
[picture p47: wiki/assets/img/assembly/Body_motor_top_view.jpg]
Body motor top view showing all cables inside the body, before shell is fitted


### Step 23: Install battery

Place the **rubber pad** into the bottom of the LiPo cage first. This pad provides vibration dampening and prevents the LiPo pouch from chafing against the printed plastic. Slide the **LiPo 2S** battery into the cage. The balance connector and main connector should exit from the open end.

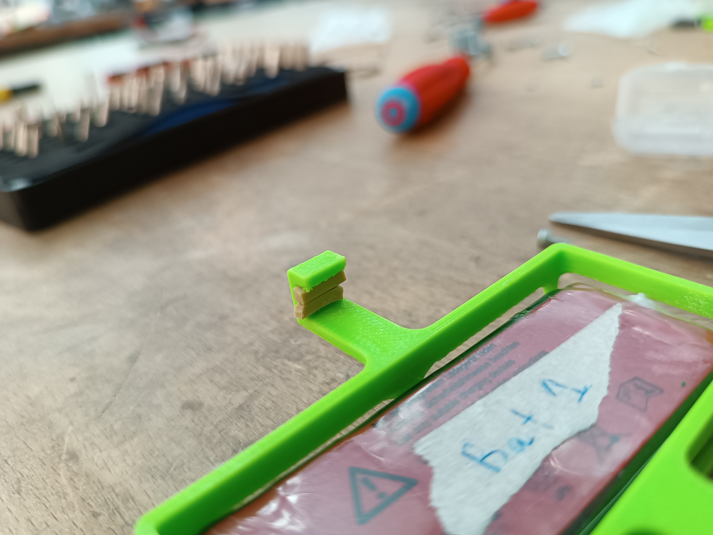
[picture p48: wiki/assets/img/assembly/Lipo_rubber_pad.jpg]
LiPo battery in the printed cage with rubber pad visible at the connector end


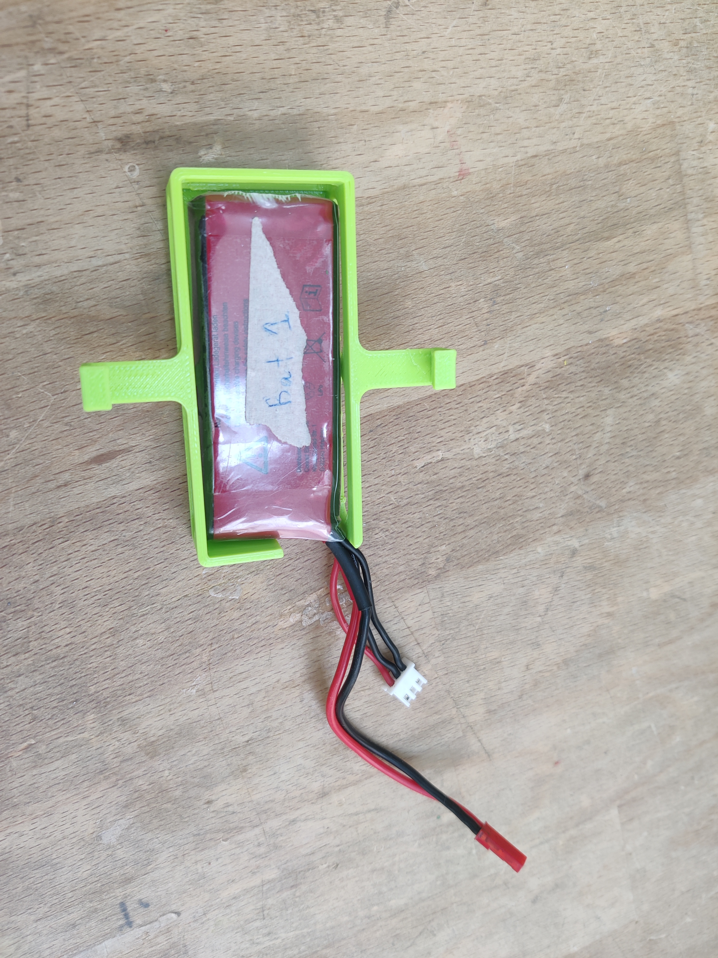
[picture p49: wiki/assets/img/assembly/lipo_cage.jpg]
LiPo in cage, full view, showing both the main power lead (red JST) and the balance lead


Clip or slide the LiPo cage into the underside of the body frame.

!!! danger "Battery safety: read carefully"
    - **Never short the battery leads.** Even briefly touching + and − together can cause fire.
    - **Check polarity before connecting.** The main connector on this build uses a JST connector (red = +, black = −). Verify your connector matches before plugging in.
    - **Do not connect the battery yet.** Only connect it in the very next step, after everything else is complete and double-checked.
    - **Never leave a LiPo charging unattended.**
    - **Store LiPo at storage voltage (~3.8V/cell)** if not using the robot for more than a few days.

### Step 24: Final checks before power-on

Go through this checklist methodically before plugging in the battery:

- [ ] All 12 servo cables are plugged into the PCA9685, correct orientation (GND to outside edge)
- [ ] I²C bus connected: ESP32 → OLED, IMU, PCA9685 (and ToFs if fitted)
- [ ] Buck Converter output connected to ESP32 5V input
- [ ] BMS connected between battery connector and the rest of the power chain
- [ ] Capacitor wired in parallel, polarity correct
- [ ] All screws on leg joints are tightened but not cracked
- [ ] All ball bearings spin freely
- [ ] No servo cables are pinched in a joint or taut across a range of motion
- [ ] ESP32 USB-C port is accessible for firmware flashing
- [ ] No loose wires or uninsulated joints inside the body cavity

### Step 25: Connect the battery and fit the shell

Once every item above is checked, connect the **balance lead** first (smaller white connector), then the **main power lead** (larger red JST). The OLED should light up and the ESP32's onboard LED should blink.

If anything smells burnt or a board gets hot immediately, **disconnect the battery at once** and inspect for reversed polarity or a short circuit.

Once you confirm the electronics are responding normally, fit the **shell** over the top of the body by pressing it down onto the mounting clips.

Completed FaceHugger with shell fitted, top view

## Finished robot

**Congratulations, your FaceHugger is assembled!**

Completed FaceHugger, full top view with shell

Completed FaceHugger, top view without shell showing all internals

Side view showing hip servos and body depth

Top-down body view showing all four hip servos and internal wiring

The next step is flashing the firmware to the ESP32 and calibrating the servo zero positions. Refer to the [Software](software.md) and [Calibration](calibration.md) sections of this documentation.

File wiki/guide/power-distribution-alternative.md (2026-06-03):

# Alternative Power Distribution: Copper Board

!!! info "Context - why this page exists"
    This page documents an alternative power distribution setup that was explored
    during development but was not carried forward into the final build. It is
    preserved here so that future builders who run into the same power distribution
    problems we faced have a concrete, validated alternative to reference. It is
    one of several approaches that could work, not a recommendation.

---

## The problem

The standard approach of routing servo power through the PCA9685's onboard V+
and GND traces has a fundamental limitation: those traces are not rated for the
combined current draw of 12 high-torque servos under load. Under aggressive
movement or simultaneous multi-leg actuation, this causes voltage drops, brownouts,
and in the worst case, permanent damage to the multiplexer board. In the end, we burnt 
two PCA Multiplexers.

The question is how to deliver raw LiPo current to all 12 servos reliably,
without routing it through the PCA9685 traces, while keeping the assembly compact
enough to fit inside the shell.

---

## The solution: custom copper power board

The approach taken here was to fabricate a small custom power distribution board
using copper stripboard. The board acts as a dedicated power bus, sitting between
the BMS output and the servo connectors, completely bypassing the PCA9685's power
traces. 

**Key design decisions:**

- **Leg blocks spaced to mirror the PCA9685 pin layout** - the servo connector
  positions on the copper board match the physical layout of the multiplexer,
  keeping cable runs short and tidy
- **BMS power cables soldered directly to the board** - eliminates an intermediate
  connector and reduces resistance in the high-current path
- **Only two rows of pin headers soldered** - V+ and GND only; PWM is handled
  separately (see below)
- **PWM routed independently** - each servo's PWM signal wire connects directly
  from the servo's female connector to the PCA9685 using a male-to-female jumper,
  keeping the signal path entirely separate from the power path
- **GND bridge between copper board and PCA9685** - a dedicated GND wire ties the
  copper board's ground plane to the PCA9685's GND, ensuring a common reference
  for the PWM signals. This is easy to forget and causes erratic servo behaviour
  if omitted

---

## Build notes

This is not a step-by-step guide, but the following points are worth knowing
before attempting this approach:

- Plan the strip layout carefully before soldering - cut the copper strips between
  V+ and GND rows to prevent shorts before any wire is attached
- Test continuity and check for shorts with a multimeter before connecting the BMS
- The board is compact enough that the shell fits over the assembly without
  modification
- Cable management becomes more involved with this setup due to the additional
  PWM jumper wires - allow extra time for routing and securing them

Here are a few pictures of the setup :
[Top of copper board](../assets/img/copper-board/top_board.jpg)
[Bottom of copper board](../assets/img/copper-board/bottom_board.jpg)
[Full setup top view](../assets/img/copper-board/full_setup.jpg)

---

## What we learned

The setup was validated by running all previously working functionality after the
rebuild and everything behaved correctly. The main takeaways for anyone considering
this approach:

- It works, but it adds complexity to the wiring compared to using terminal blocks
- The GND bridge between the copper board and the PCA9685 is **not optional** -
  without it the PWM signals have no common ground reference and servo behaviour
  is undefined
- Spacing the connector rows to match the PCA9685 layout is worth the extra
  planning time - it makes the final wiring significantly cleaner
- Other valid alternatives exist: Wago connectors, Domino terminal blocks, or a
  purpose-made PCB would all solve the same problem with different trade-offs in
  cost, complexity, and space

---

## See also

- [Parts & Materials - Electronics](parts.md#electronics) for the recommended
  final build power distribution approach
- [Assembly - Body + Sensors](assembly.md) for how power wiring fits into the
  full build sequence

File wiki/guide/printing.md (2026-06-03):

# 3D Printing

## Printer & filament

All prints were made at the **SPOT**, EPFL's makerspace. The SPOT provides preconfigured PrusaSlicer profiles for their printers - download them from the SPOT website before slicing. They have both **MK3S** and **MK4S** printers; make sure to select the correct model in PrusaSlicer.

## Print settings

Our prints only use **SPOT-PETG** filament with **0.20 mm** layer height. Whether you use **STRUCTURAL** or **SPEED** settings is up to your timing - they yield similar results, but prefer **STRUCTURAL** if you are not in a hurry. Leave infill at the default 15%.

Most parts need paint-on supports (Smart fill, 30°) on specific faces - see each part section below for which faces to paint. Do not use automatic support generation.

## Part viewer

Use this to inspect each part in 3D and confirm the print orientation before slicing.

<style>
.stl-viewer-root {
  display: flex;
  gap: 1rem;
  align-items: flex-start;
  margin: 1.5rem 0;
}
.stl-viewer-list {
  display: flex;
  flex-direction: column;
  gap: 0.25rem;
  min-width: 148px;
}
.stl-viewer-list .stl-group-label {
  font-size: 0.7rem;
  font-weight: 600;
  letter-spacing: 0.05em;
  text-transform: uppercase;
  color: var(--md-default-fg-color--light, #888);
  padding: 0.5rem 0.25rem 0.1rem;
}
.stl-viewer-list button {
  background: var(--md-code-bg-color, #f5f5f5);
  border: 1px solid var(--md-default-fg-color--lightest, #ddd);
  border-radius: 4px;
  padding: 0.35rem 0.75rem;
  text-align: left;
  cursor: pointer;
  font-size: 0.85rem;
  font-family: var(--md-code-font, monospace);
  transition: background 0.15s;
}
.stl-viewer-list button:hover {
  background: var(--md-accent-fg-color--transparent, #e0e0e0);
}
.stl-viewer-list button.stl-active {
  background: var(--md-primary-fg-color, #e65100);
  color: #fff;
  border-color: transparent;
}
model-viewer {
  flex: 1;
  min-width: 0;
  height: 380px;
  border-radius: 6px;
  border: 1px solid var(--md-default-fg-color--lightest, #ddd);
  background: #f0f0f0;
}
</style>

<script type="module" src="https://ajax.googleapis.com/ajax/libs/model-viewer/3.5.0/model-viewer.min.js"></script>

<div class="stl-viewer-root" markdown="0">
  <div class="stl-viewer-list">
    <span class="stl-group-label">Body</span>
    <button data-model="../../assets/models/BodySkeleton.glb">BodySkeleton</button>
    <button data-model="../../assets/models/MiddleBridge.glb">MiddleBridge</button>
    <button data-model="../../assets/models/BehindBridge.glb">BehindBridge</button>
    <button data-model="../../assets/models/HipMount.glb">HipMount</button>
    <button data-model="../../assets/models/LipoCage.glb">LipoCage</button>
    <button data-model="../../assets/models/Shell.glb">Shell</button>
    <span class="stl-group-label">Legs</span>
    <button data-model="../../assets/models/Link1L.glb">Link1L</button>
    <button data-model="../../assets/models/Link1R.glb">Link1R</button>
    <button data-model="../../assets/models/Link2.glb">Link2</button>
    <button data-model="../../assets/models/Link3.glb">Link3</button>
  </div>
  <model-viewer camera-controls auto-rotate
                environment-image="neutral"
                shadow-intensity="1" shadow-softness="0.1"
                exposure="0.7"
                camera-orbit="45deg 70deg auto"
                style="width:100%;height:380px;"></model-viewer>
</div>

## Body parts

`BodySkeleton.stl` :

Do not change the orientation that appears when you first import the file in PrusaSlicer.

You must add **paint-on supports** (Smart fill, 30°) under every uncovered zone, including under the ESP32 hood and the little Lipo protector wing. Make sure to only paint supports - do not use automatic support generation. Do not paint inside the screw holes.

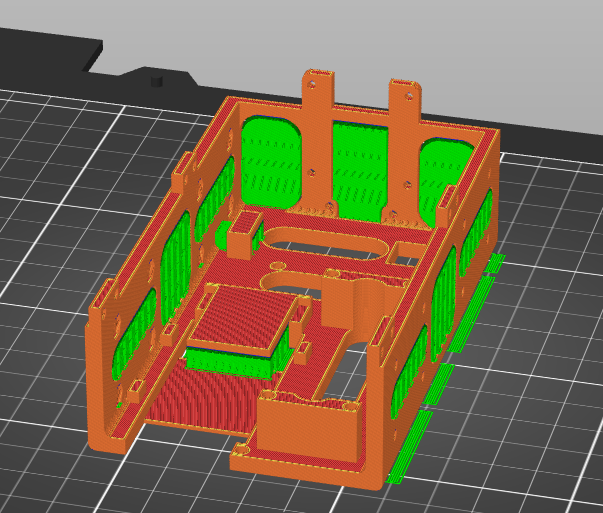
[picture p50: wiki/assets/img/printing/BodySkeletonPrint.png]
The body in Prusa-slicer


`Middle_bridge.stl` and `Behind_bridge.stl` : Print as is.

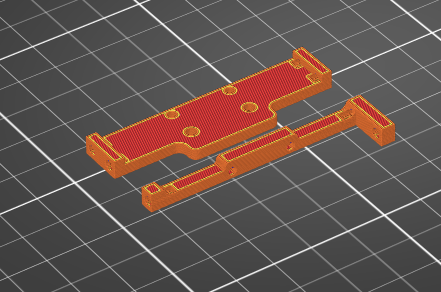
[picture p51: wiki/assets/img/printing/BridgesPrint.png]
The bridges in Prusa-slicer


`HipMount.stl` :

Print with the back (largest surface) of the mount on the print bed. Add paint-on supports (Smart fill, 30°) to the face with the hex nut recess. Do not paint inside the recess itself.

Before printing, copy the file once and mirror it along the back axis - you need a total of 4 hip mounts (2 mirrored pairs).

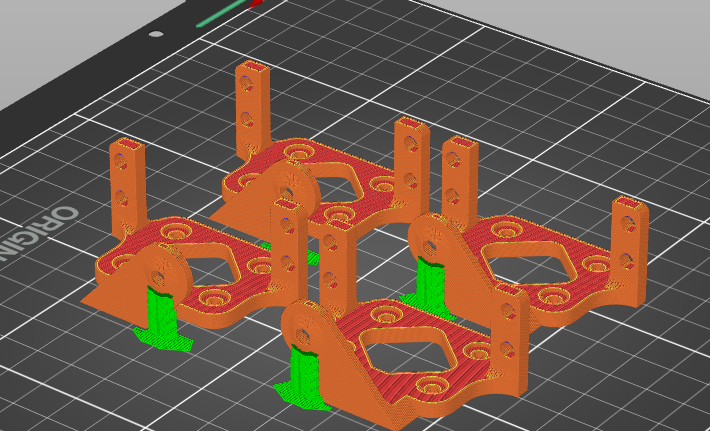
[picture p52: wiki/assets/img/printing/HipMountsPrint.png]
The hip mounts in Prusa-slicer


`Shell.stl` :

Do not forget to add supports on every surface facing the printing board, including the little surfaces above the hooks.

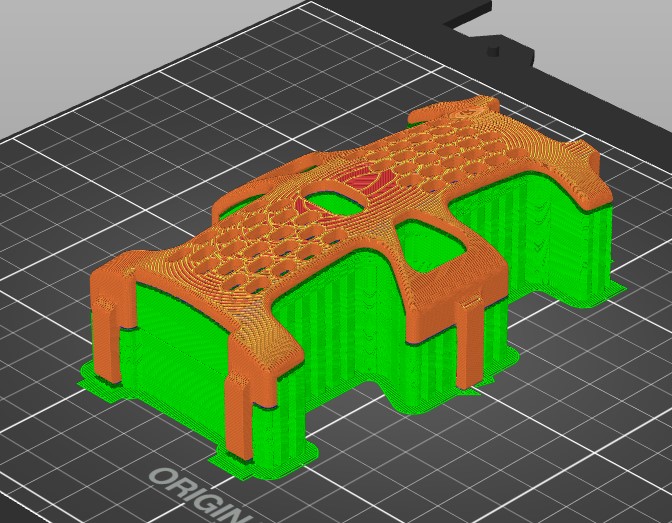
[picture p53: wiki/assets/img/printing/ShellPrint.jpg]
The shell in Prusa-slicer


``LipoCage.stl` :

Print with supports in the empty side slots. Do not forget the supports for the arms and hooks.

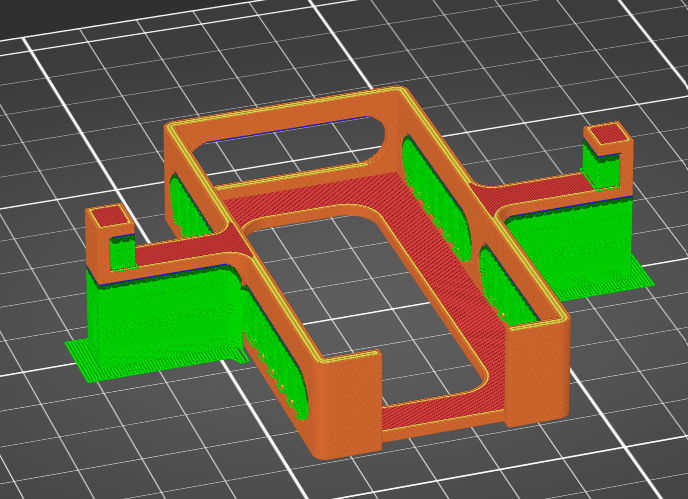
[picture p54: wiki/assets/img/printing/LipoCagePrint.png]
The lipo cage in Prusa-slicer


## Leg parts

The leg `.3mf` files are pre-plated with the correct orientation already set, so open them in PrusaSlicer directly without adjusting anything.

All leg parts use **paint-on supports → Smart fill → 30°**. Do not use automatic support generation - only paint the faces shown below.

`Link1L.stl` and `Link1R.stl` :

Print standing upright as exported. Paint supports on the top bridge face and the servo mount face as shown below. Link1L and Link1R are mirrored - both are on the same plate in the `.3mf`.

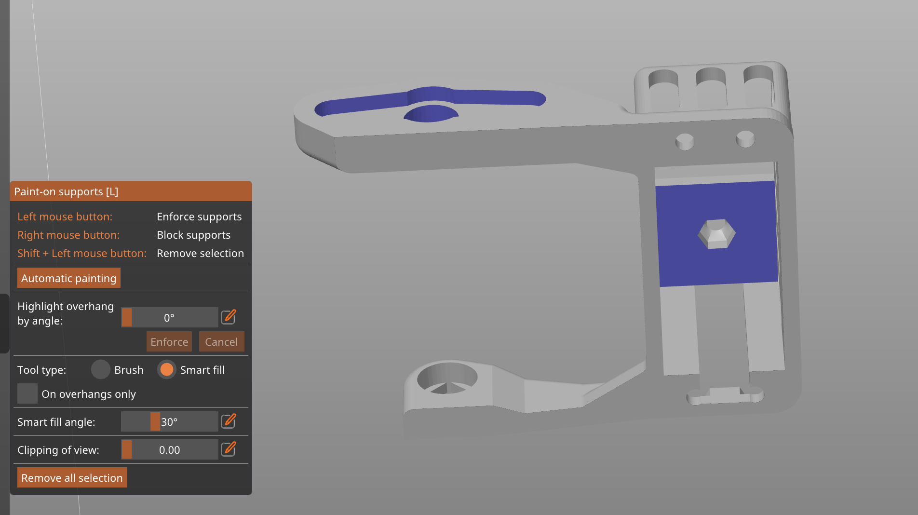
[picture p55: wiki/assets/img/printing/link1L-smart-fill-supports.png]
Link1L smart-fill support zones

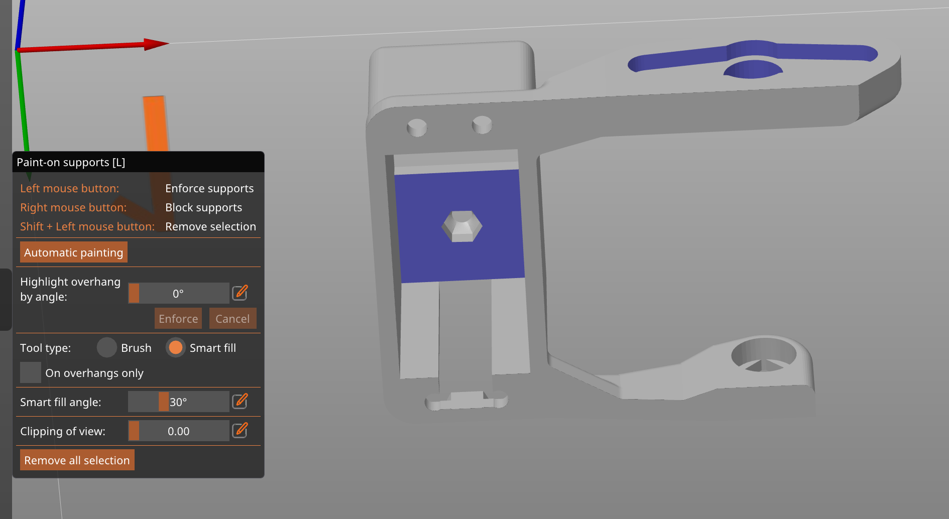
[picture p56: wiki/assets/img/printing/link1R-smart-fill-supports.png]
Link1R smart-fill support zones


`Link2.stl` :

Print flat. Paint supports under the two bridge overhangs at the top face.

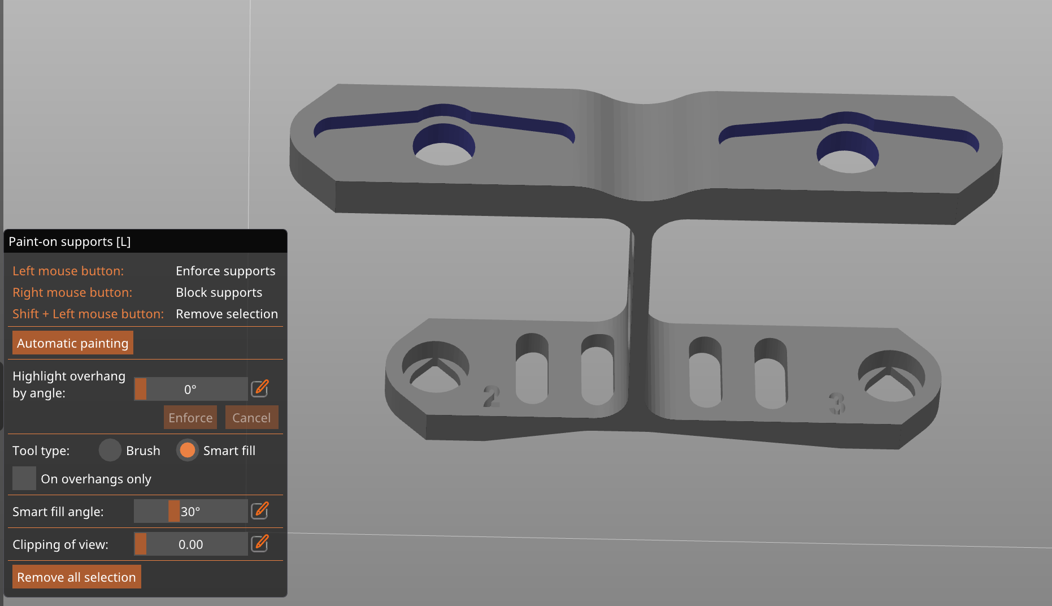
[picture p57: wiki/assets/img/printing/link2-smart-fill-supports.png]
Link2 smart-fill support zones


`Link3.stl` :

Print as exported (tip facing up). Paint one support zone on the servo pocket face at the heel end.

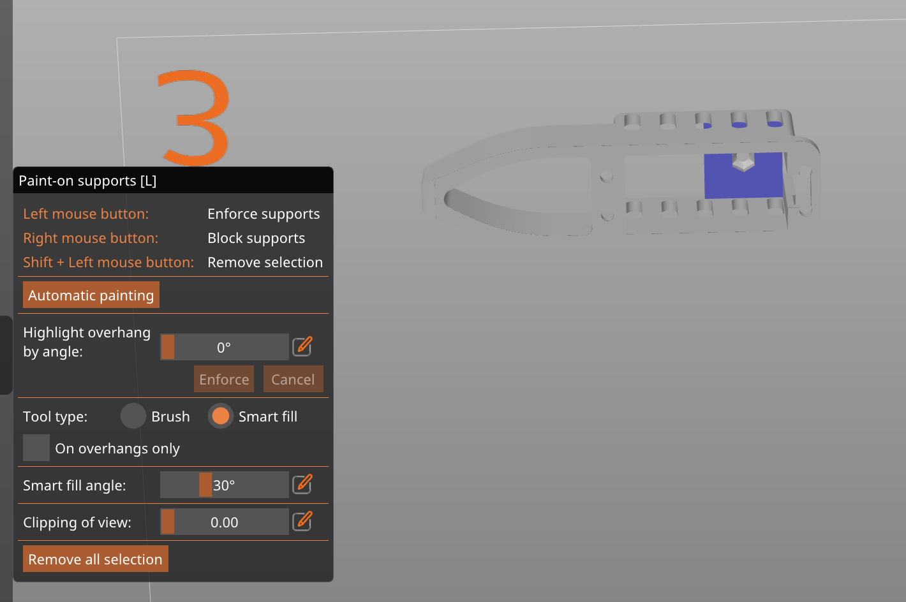
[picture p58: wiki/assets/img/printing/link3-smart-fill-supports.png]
Link3 smart-fill support zones


### Expected print times

The table below is from PrusaSlicer with the full 4-leg set (3 plates) on an **MK4S**. The two print mode columns correspond to the SPEED and STRUCTURAL SPOT profiles.

| Plate | Filament | SPEED profile | STRUCTURAL profile |
|---|---|---|---|
| Bed 1 | 72 g / 23.6 m | 4 h 19 min | 5 h 14 min |
| Bed 2 | 59 g / 19.4 m | 3 h 39 min | 4 h 27 min |
| Bed 3 | 67 g / 21.9 m | 3 h 40 min | 4 h 41 min |
| **Total** | **199 g / 65 m** | **11 h 39 min** | **14 h 22 min** |

Budget roughly half a day for all leg parts with the SPEED profile, or a full day with STRUCTURAL.

## Files

The `.3mf` files include the correct part orientation and plate layout - use these for slicing, not the raw STLs.

!!! note
    The individual STL files in `cad/leg/` and `cad/body/` are auto-generated by the Fusion exporter and committed for pipeline use. The `.3mf` files below are the user-facing print-ready versions.

**Body**

- [`cad/body/prusa/BodyAndBridges.3mf`](https://github.com/epfl-cs358/2026sp-FaceHugger/blob/main/cad/body/prusa/BodyAndBridges.3mf): body shell and both bridges on one plate
- [`cad/body/prusa/HipMount.3mf`](https://github.com/epfl-cs358/2026sp-FaceHugger/blob/main/cad/body/prusa/HipMount.3mf): all 4 hip mounts (pre-mirrored)
- [`cad/body/prusa/ShellPrint.3mf`](https://github.com/epfl-cs358/2026sp-FaceHugger/blob/main/cad/body/prusa/ShellPrint.3mf): decorative shell

**Legs**

`FHLegsPrintThreePlates.3mf` contains the full 4-leg set across 3 plates and is the one to use for a complete build. The other files are single-leg or partial plates left from earlier iterations.

- [`cad/leg/prusa/FHLegsPrintThreePlates.3mf`](https://github.com/epfl-cs358/2026sp-FaceHugger/blob/main/cad/leg/prusa/FHLegsPrintThreePlates.3mf) - full set, 3 plates **(use this)**
- [`cad/leg/prusa/FaceHuggerLeg.3mf`](https://github.com/epfl-cs358/2026sp-FaceHugger/blob/main/cad/leg/prusa/FaceHuggerLeg.3mf)
- [`cad/leg/prusa/FHLegsLink1and2.3mf`](https://github.com/epfl-cs358/2026sp-FaceHugger/blob/main/cad/leg/prusa/FHLegsLink1and2.3mf)
- [`cad/leg/prusa/IndividualLegPrints.3mf`](https://github.com/epfl-cs358/2026sp-FaceHugger/blob/main/cad/leg/prusa/IndividualLegPrints.3mf)

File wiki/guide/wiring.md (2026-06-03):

# Electronics & Wiring

This document details the complete electrical nervous system of the FaceHugger quadruped. It covers the dual-rail power distribution strategy (Muscle vs. Logic), the I2C sensor bus, and the exact servo pin mappings.

!!! warning "Pinout may change"
    The exact pinout is not final. Treat pin assignments here as the current proposal, not a contract. Always confirm against the firmware `config.h` before wiring or soldering.

## Schematic

Circuit Schematic

### Block-by-Block Walkthrough
- **The Power Block:** Raw 2S LiPo voltage flows through the BMS. It then splits into two paths: the heavy-duty Domino blocks (for the servos) and the Buck Converter (stepping down to 5V for the ESP32).
- **The Brain (ESP32):** Powered by the 5V Buck Converter. It outputs a 3.3V logic signal to power the I2C sensors and generates the SDA/SCL signals.
- **The Servo Bus (PCA9685):** Receives 3.3V logic from the ESP32, but its `V+` rail receives raw battery voltage from the Domino blocks to drive the servos. 
- **The Sensor Bus (I2C):** The OLED (0x3C), IMU, and ToFs all share the same parallel SDA/SCL lines from the ESP32.

## Power Distribution

FaceHugger is capable of pulling over **30 Amps** during heavy dynamic movements. The traces on a standard PCA9685 multiplexer will vaporize at 10 Amps. Therefore, we strictly separate the "Muscle" power from the "Logic" power.

```mermaid
graph TD
    LiPo[2S LiPo Battery] --> BMS[Battery Management System]
    BMS --> |7.4V Heavy Current| Domino[Domino Blocks / Terminal]
    BMS --> |7.4V Low Current| Buck[5V Buck Converter]
    
    Domino --> |7.4V V+| Servos[12x DSS 230mg Servos]
    Domino --> |7.4V V+| Cap[2200µF 35V Capacitor]
    
    Buck --> |5V VIN| ESP32[ESP32 Microcontroller]
    ESP32 --> |3.3V Logic| PCA[PCA9685 Multiplexer]
    ESP32 --> |3.3V Logic| Sensors[OLED, IMU, ToFs]
```

- **The Muscle (Domino Bypass):** The Red (V+) and Brown (GND) wires from the servos do not plug into the PCA9685. They are routed directly to heavy-duty Domino blocks wired to the LiPo. Only the Yellow (PWM) signal wires plug into the PCA9685.
- **The Capacitor:** A massive 2200µF (35V) electrolytic capacitor is wired in parallel across the Domino block V+ and GND rails to absorb instantaneous inrush current and prevent logic brownouts.

## Servo Wiring

The Yellow (PWM) signal wires from the 12 servos connect to the PCA9685 multiplexer. Ensure you map the physical legs exactly to these hardware channels, or the Inverse Kinematics math will actuate the wrong joints.

| Leg ID | Hip Channel | Thigh Channel | Knee Channel |
| :--- | :--- | :--- | :--- |
| **Front Right (FR)** | 8 | 9 | 10 |
| **Front Left (FL)** | 12 | 13 | 14 |
| **Back Right (BR)** | 4 | 5 | 6 |
| **Back Left (BL)** | 0 | 1 | 2 |

## ESP32 Pinout

All peripheral communication is handled via a single I2C bus. The ESP32's native hardware I2C pins are split into custom cable trees (1 Female to 3+ Females) to connect all devices in parallel.

| ESP32 Pin | Function | Connects To |
| :--- | :--- | :--- |
| **VIN / 5V** | Main Logic Power In | 5V Output from Buck Converter |
| **GND** | Common Ground | Buck Converter, I2C Tree GND, PCA9685 GND |
| **3V3** | Sensor Power Out | OLED (VCC), IMU (VCC), ToFs (VCC), PCA9685 (VCC) |
| **GPIO 21** | I2C SDA (Data) | OLED, IMU, ToFs, PCA9685 (SDA pins) |
| **GPIO 22** | I2C SCL (Clock) | OLED, IMU, ToFs, PCA9685 (SCL pins) |

## Battery & Connector Safety

!!! danger "Read before powering on"
    High-current robotics require strict safety protocols. Failure to follow these steps will result in destroyed electronics or LiPo fires.

1. **Never Power Servos via the Multiplexer:** Pushing 30A through the PCA9685's green screw terminal will instantly melt the internal copper traces and likely destroy the ESP32 via ground-loop backflow. Use the Domino blocks.
2. **Polarity Check:** Verify the polarity of the 2200µF capacitor before connecting the battery. The white stripe (negative) must go to GND. Plugging an electrolytic capacitor in backward will cause it to violently rupture.
3. **I2C Separation:** Ensure the 3.3V logic cable tree NEVER touches the 7.4V battery power rails. 
4. **Power Sequence:** The 2S LiPo battery must be the absolute last thing connected. 

## Charging Your LiPo

Properly charging your 2S LiPo battery is critical for both the lifespan of the battery and your safety. The images below demonstrate a standard multi-chemistry balance charger (like an IMAX B6). 

!!! warning "LiPo Charging Safety"
    **Never leave a charging LiPo unattended.** Always charge it inside a fireproof LiPo safe bag on a non-flammable surface. If the battery ever begins to puff or swell, immediately stop the charge and move it outside.

### 1. Connect the Main Power Leads
Always connect the main output cables to the charger before plugging in the battery to prevent short circuits.
- Insert the **Red (Positive)** banana plug into the red output port on the charger.
- Insert the **Black (Negative)** banana plug into the black output port.
- Connect the other end of the cable (the red JST connector) to the main power lead of your LiPo battery.

Top View of Main Power Connections

### 2. Connect the Balance Lead
The balance lead ensures each individual cell in the 2S battery charges to exactly the same peak voltage (4.20V per cell). Skipping this step can lead to a catastrophic cell overcharge.
- Locate the small white balance connector on the battery (it has 3 wires for a 2S battery).
- Plug this into the **2-cell** balance socket on the side of the charger. The plug has alignment rails, so do not force it; it will only slide in one way.

Side View of Balance Lead Connection

### 3. Configure the Charger Settings
Once both the main power and balance cables are securely connected, configure the charger interface:
- **Mode:** Navigate to `LiPo BALANCE CHG` mode (do not use standard "Charge" or "Fast Charge").
- **Voltage/Cells:** Set to `2S` (7.4V).
- **Current:** Set the charge current to a safe **1C** rate (1x the battery's capacity in Amps). For a 1000mAh battery, set the current to **1.0A**.
- Press and hold the `Start/Enter` button to initiate the battery check. The charger will ask you to confirm that its detected cell count matches your setting. Press Enter again to begin charging.

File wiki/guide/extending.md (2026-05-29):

# Next steps and extending FaceHugger

FaceHugger is a working robot, but it is also a starting point. This page collects what we would do next and how someone else could build on it. If you are picking the project up, the [Reference](../reference/conventions.md) section is where the architecture is explained in depth; this page is the shorter "what now" view.

## Future directions

FaceHugger walks, but there is a lot of room to take it further. These are the directions we would explore next. Each is a project in its own right, sketched here as a starting point rather than a finished plan.

- **More sensing.** Add sensors beyond the current ToF and IMU, and close the loop on them so the robot reacts to its surroundings rather than just reading them.
- **IMU stabilization and correction.** Use the IMU to keep the body level and adjust the gait in real time, so the robot stays balanced on uneven ground or when nudged.
- **Better walk cycles and animation.** Refine the gaits and author smoother, more lifelike clips for richer and more natural motion.
- **A camera for navigation.** Add a camera so the robot can perceive and navigate its environment instead of being driven blind.
- **A redesign around the center of gravity.** Revisit the mechanical design to bring the motors closer to the body and lower the center of gravity, which would make balance and dynamic motion much easier.

These are deliberately high level. We would expand each into its own design and milestones before building it.

## Tips for expanding the project

The architecture is built so each piece can be extended without touching the others. A few entry points:

- **Add a new gesture (clip).** Pose it on the Blender rig, save it as a clip in the FH Clip Panel, export, copy the bundled `clips_all.h` into the firmware tree, and reflash. The full path is in [Blender to robot clips](../reference/animation/clip-panel.md).
- **Add or tune a gait.** Gaits are phase-based angle schedules in the firmware (`tickGait` / `tickTrot`), parameterized by step length, height, period, and duty. The [firmware reference](../reference/firmware/index.md) explains the motion engine.
- **Extend the control API.** Add a new `T:N` command by handling it in the firmware's `network.cpp`. Because the simulator's `serve` runs the exact compiled firmware, your new command works in the sim immediately, with no separate mock to update. See the [WebSocket API](../reference/remote-control/websocket-api.md).
- **Validate in simulation first.** Anything you change in the firmware or the clips can be checked in PyBullet before it reaches hardware, including driving the sim from the real mobile app. See the [simulation section](../reference/simulation/index.md).

## Make it yours

If you fork or extend FaceHugger, the conventions in the [Reference](../reference/conventions.md) are the contract that keeps the CAD, firmware, animation, and simulation in agreement. Keep that contract and the rest of the system stays consistent as you build on it.

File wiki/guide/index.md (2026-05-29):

# Build Guide

This guide walks through building a FaceHugger from parts to a walking robot: what to print, how to wire it, how to assemble it, and how to bring up the software. If you want to understand how the system works rather than build it, see the [Reference](../reference/index.md) instead.

The pages roughly follow the build order, but you can jump to whichever stage you are at.

<div class="grid cards" markdown>

-   :material-cube-outline:{ .lg .middle } __Design and parts__

    ---

    What FaceHugger is, the bill of materials, and what you need to print.

    [:octicons-arrow-right-24: Design](design.md) · [Parts](parts.md) · [Printing](printing.md)

-   :material-screwdriver:{ .lg .middle } __Build it__

    ---

    Wire the electronics and assemble the legs and body into a working robot.

    [:octicons-arrow-right-24: Wiring](wiring.md) · [Assembly](assembly.md)

-   :material-laptop:{ .lg .middle } __Bring up the software__

    ---

    Flash the firmware, calibrate the servos, and drive the robot from the app.

    [:octicons-arrow-right-24: Software](software.md) · [Calibration](calibration.md) · [Remote control](remote_control_app.md)

-   :material-tools:{ .lg .middle } __Toolchain and beyond__

    ---

    The CAD-to-firmware pipeline for authoring new motion, and where to take the project next.

    [:octicons-arrow-right-24: Toolchain](toolchain/index.md) · [Next steps](extending.md)

</div>

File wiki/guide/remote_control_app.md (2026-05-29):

# Remote Control App

The FaceHugger remote control app is a mobile application (React Native / Expo) that communicates with the ESP32 over Wi-Fi. It gives you three modes of control: a joystick for driving, one-shot action buttons, and per-servo angle control for calibration.

## What you need

| Item | Notes |
|---|---|
| Android or iOS phone | Android 10+ / iOS 14+ |
| Node.js 18+ | Only needed if running from source or Expo Go |
| Expo Go app | [Android](https://play.google.com/store/apps/details?id=host.exp.exponent) / [iOS](https://apps.apple.com/app/expo-go/id982107779) (only for Option A below) |
| Pre-built APK (optional) | Only for Option B (get it from the project team) |

## Installing the app

=== "Option A: Expo Go (no build required)"

    Expo Go lets you run the app directly from the development server without building an APK.

    1. Install **Expo Go** on your phone from the links above.
    2. Clone the repo and install dependencies on your computer:

    ```bash
    cd code/remote-control-app/MyApp
    npm install
    npm run start
    ```

    3. A QR code will appear in the terminal. Scan it with Expo Go (Android) or the Camera app (iOS).

    The app loads on your phone and hot-reloads on every source change, which is useful while developing.

=== "Option B: Android APK sideload"

    If you have a pre-built `.apk` file, you can install it directly without the development server.

    !!! warning "Allow unknown sources"
        Before installing an APK outside the Play Store, you must allow it in Android settings:
        **Settings → Security → Install unknown apps**, then grant permission to your file manager.

    1. Transfer the `.apk` file to your phone (USB cable, Google Drive, etc.).
    2. Open the file on your phone and tap **Install**.
    3. Launch **FaceHugger** from your home screen.

    !!! note
        APK sideloading is Android-only. For iOS, the app must be distributed via TestFlight or run through Expo Go.

## Connecting to the robot

The ESP32 creates its own Wi-Fi access point, so your phone must join that network, not your home Wi-Fi.

!!! warning "Disconnect from your home network first"
    iOS and Android sometimes switch back to a known network in the background. If the connection pill stays red after following the steps below, check that your phone is still on the FaceHugger network.

**Steps:**

1. Power on the robot and wait for the OLED face to appear. This confirms the Wi-Fi AP is up and the WebSocket server is listening.

2. On your phone, open **Wi-Fi settings** and join the FaceHugger network.

    <!-- photo: ../assets/img/remote-control/wifi-setup.jpg -->
    !!! example "Photo placeholder"
        *Add a screenshot here: phone Wi-Fi settings showing the FaceHugger AP selected.*

3. Open the app. The connection pill in the header should turn **green** within one or two seconds.

    <!-- photo: ../assets/img/remote-control/connected-header.jpg -->
    !!! example "Photo placeholder"
        *Add a screenshot here: app header showing the green "Connected" pill and live telemetry bar.*

!!! tip "Default needs no configuration"
    The ESP32 AP is always at `192.168.4.1`, and the app's startup default points there, so connecting to the robot needs no setup. To target the simulator or a different address, use the **Settings** screen (see [Changing the connection target](#changing-the-connection-target-ip-and-port)).

## App overview

Every page shares a **persistent header** at the top:

| Section | What it shows |
|---|---|
| Logo | FaceHugger branding |
| Connection pill | Green "Connected" / red "Not Connected" |
| Telemetry bar | Gait mode · Speed (m/min) · Gyroscope X/Y/Z · error message if any |

The telemetry bar is hidden while disconnected. It is populated by the `T:10` status packets the robot sends every ~500 ms.

Three pages are selected from a **bottom tab bar**.

## Page 1: Remote Control

The main driving interface. Switching to this tab sends `STATE_WALK` to the robot, enabling the gait engine.

<figure markdown="span">
  Remote Control screen
  <figcaption>Remote Control page: joystick centred, TROT gait selected</figcaption>
</figure>

### Joystick

Drag in any direction to steer. The joystick maps angular sectors to eight direction commands:

| Direction | Command |
|---|---|
| Up | Forward |
| Up-right / Up-left | Forward-right / Forward-left |
| Right / Left | Strafe right / Strafe left |
| Down-right / Down-left | Backward-right / Backward-left |
| Down | Backward |

Releasing the joystick sends a **STOP** command. The robot also has a built-in 2-second timeout: if no movement command arrives while in `STATE_WALK`, it stops automatically.

### Gait mode

The dropdown in the bottom-right corner switches between two gaits:

| Mode | Description |
|---|---|
| **TROT** | Diagonal pairs move together for a faster, natural walking gait |
| **CRAB** | Legs move more independently for lateral and omnidirectional travel |

Selecting a gait sends the change immediately and is remembered across reconnects.

## Page 2: Actions

One-shot commands that put the robot into `STATE_ACTION`.

<figure markdown="span">
  Actions screen button
  <figcaption>Actions page: Invert robot button</figcaption>
</figure>

<figure markdown="span">
  Actions screen confirm prompt
  <figcaption>Confirmation prompt before the invert command is sent</figcaption>
</figure>

| Button | What it does |
|---|---|
| **Invert robot** | Toggles the inverted (upside-down) flag and flips the current pose in place, mirroring the pitch joints and easing over ~300 ms. Press again to flip back. A confirmation prompt appears before the command is sent. |
| **Rest pose** | Drives all 12 servos to 90°, a neutral reset useful before calibration. |
| **Neutral stance** | Brings the robot to its standard standing pose using the default angles from the firmware. |

!!! note "Invert mirrors the live pose, it is not a self-righting maneuver"
    Invert flips whatever pose the robot is currently holding (pitch mirrored, shoulder unchanged); it does not run an authored get-up sequence. It is meant for driving while physically upside-down. There is no automatic orientation sensing yet, so flip it manually to match the robot's real orientation.

## Page 3: Individual Control

Direct per-servo angle control, used for calibration. Switching to this tab sends `STATE_IDLE`, so the gait engine turns off and servos hold position.

<figure markdown="span">
  Individual Control screen
  <figcaption>Individual Control page: leg and servo selectors, angle input</figcaption>
</figure>

**Workflow:**

1. Select a leg: **Front Right** · **Front Left** · **Back Right** · **Back Left**.
2. Select a servo: **Hip** · **Thigh** · **Knee**.
3. Enter an angle (0-180°) and tap **Send angle**.

Each tap sends a single calibration packet to that servo. The input field remembers the last-sent angle for each leg/servo pair within the session, so switching between servos restores the last value you committed.

!!! tip "Use this page during servo calibration"
    After assembly, send each servo to 90° with the Rest pose button (Page 2), then use this page to fine-tune individual joints. See [Calibration](calibration.md) for the full procedure.

## Changing the connection target (IP and port)

The app connects to one WebSocket target, and you can change it at runtime from the **Settings** screen (gear icon): tap the **Robot** preset (`192.168.4.1:81`, the ESP32 AP) or the **Simulator** preset (`localhost:8081`, the PyBullet `sim --serve`), or type any IP and port and tap **Connect**. Switching reconnects immediately.

You only need to leave the Robot preset if the ESP32 is on a router in station mode (use the IP the router assigned, from the serial monitor) or if you are driving the [simulator](../reference/simulation/pybullet-control.md#sim-serve-drive-the-sim-like-the-robot).

The startup default and the two presets are defined in `code/remote-control-app/MyApp/config/config.ts` (`DEFAULT_IP` / `DEFAULT_PORT`, `ROBOT_*`, `SIM_*`). When running the app as a web page, the host port is set by the `--port` flag in the `web` npm script (`expo start --web --port 8080`); edit that number, or run `npx expo start --web --port <p>`.

## Troubleshooting

| Symptom | Likely cause | Fix |
|---|---|---|
| Header pill stays red | Phone is not on the robot's Wi-Fi network | Open Wi-Fi settings and join the FaceHugger AP |
| App connects but robot doesn't respond to joystick | Robot is still in `STATE_IDLE` | Swipe to the Remote Control tab, which triggers `STATE_WALK` |
| Robot stops moving after ~2 seconds of holding still | Firmware 2-second idle timeout (intentional) | Keep dragging the joystick to sustain movement |
| Invert button does nothing | A second press within 250 ms is debounced; or the robot was upright so the mirrored pose looked wrong | Wait a moment between presses; flip only when the robot is actually upside-down |
| Telemetry bar stays hidden after connecting | `T:10` status packets not arriving | Check the serial monitor, as the firmware may have crashed; power-cycle the robot |
| Expo Go can't load the app (version mismatch) | Expo Go is outdated | Update Expo Go from the App Store / Play Store, then re-run `npm run start` |
| `npm install` fails with native module errors | Node version too old | Use Node 18+; run `node --version` to check |

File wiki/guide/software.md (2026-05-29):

# Software

## Overview

FaceHugger spans several toolchains that meet at one shared contract (the conventions and the WebSocket protocol). The pieces are:

| Component | Language / tooling | Where |
|---|---|---|
| Firmware | C++ (Arduino), built with **PlatformIO** for the ESP32 | `code/firmware/` |
| Simulation | **Python 3.12** + PyBullet (a conda env, see below) | `code/simulation/` |
| Animation | **Blender 5.1** (its own bundled Python) + a Fusion 360 export script | `animation/`, `cad/scripts/` |
| Remote control app | **React Native / Expo** (TypeScript) | `code/remote-control-app/MyApp/` |
| Mechanical design | **Fusion 360** + the printable-STL export script | `cad/` |

The three software components that run code are the embedded C++ firmware on the ESP32, a host-side PyBullet simulation, and the mobile remote-control app. The animation and CAD tooling run inside Blender and Fusion 360 respectively, using those applications' own bundled Python, so they need no environment of their own.

### Firmware architecture (ESP32)

The firmware lives under `code/firmware/src/`: four module folders plus the top-level `main.cpp`.

| Module | Role |
|---|---|
| `nervous_system/` | Coordinates the whole robot body: legs, screen, servos, gaits, and clip playback |
| `brain/` | High-level external communication: receiving and processing packets, handling sensor I/O |
| `shared/` | Configuration and data types shared across modules |
| `display/` | Assets and utility files for the screen |
| `main.cpp` | Initialises and continuously updates `nervous_system` and `brain` |

**`nervous_system/`**

- `spinal_cord.cpp/h`: software abstraction for full limb coordination; implements the gaits, the baked-clip player, invert (a pose mirror), and the state machine
- `leg.cpp/h`: software abstraction for a single leg
- `kinematics.cpp/h`: IK math, kept for reference and tested against the simulation. Locomotion does not use runtime IK: gaits are phase-based angle schedules and gestures are baked clips
- `servo.cpp/h`: software abstraction for servo control (angles and PWM pulses)
- `face.cpp/h`: software abstraction for screen display and updates
- `movements.h`: enums for the module: Leg IDs, gait parameters and types, action types
- `README.md`: summary of the module

**`brain/`**

- `network.cpp/h`: handles all external communication with the app: receives and
  parses packets, creates the Wi-Fi hotspot, manages WebSocket connections
- `diagnostics.cpp/h`: spins up a lightweight HTTP server (port defined by
  `diagnostics::kHttpPort`) that exposes a rolling CSV log of the robot's internal
  state; samples a `SpinalCord::Snapshot` at a fixed interval and appends it to an
  in-memory ring buffer
- `csv_log.h / csv_log.cpp`: ring buffer and CSV serialisation layer used by
  `diagnostics`; each row captures a full snapshot of the robot at a point in time

    The diagnostics HTTP endpoints are:

    | Endpoint | Method | Description |
    |---|---|---|
    | `/` | `GET` | Lists available endpoints |
    | `/log` | `GET` | Returns the CSV header followed by the full rolling buffer |
    | `/log/clear` | `POST` | Clears the ring buffer |

    The CSV log contains the following columns:

    | Column | Description |
    |---|---|
    | `millis` | Timestamp in milliseconds since boot |
    | `robot_state` | Current FSM state |
    | `gait` | Active gait type |
    | `is_moving` | `1` if the robot is executing a gait, `0` if standing |
    | `is_inverted` | `1` if the robot is detected as upside-down |
    | `last_cmd_ms` | Timestamp of the last received command |
    | `target_x/y/yaw` | Commanded velocity setpoints |
    | `active_x/y/yaw` | Currently executing velocity values |
    | `fr/fl/br/bl_hip/thigh/knee` | Servo angles (°) for all 12 joints |

**`shared/`**

- `config.h`: PCA9685 channel assignments for all limbs, default servo angles, I²C addresses
- `data.h`: command types and robot states

**`display/`**

- `assets/`: all sprites for the robot's face expressions, the corresponding PROGMEM bitmap header file, and the converter scripts

**`main/`**

- `main.cpp`: initialises and continuously updates `nervous_system` and `brain`

### Host-side tooling

**Remote control app**: built with React Native and Expo Go. Connects to the ESP32's hotspot and sends lightweight JSON packets over WebSockets to trigger gaits, individual limb control, and special actions (invert (a pose mirror), clip playback, etc.).

**Simulation**: a PyBullet physics environment for testing gaits, clips, and weight distribution offline before deploying to hardware. It can run the exact compiled firmware in the loop (software-in-the-loop), so what you validate in the sim is the same C++ that runs on the robot. See the [simulation reference](../reference/simulation/index.md).

**`API_SPEC.md`**: the JSON contract describing how the app and the ESP32 communicate. The [WebSocket API reference](../reference/api.md) documents the live `T:` protocol.

## How it works

### Boot sequence

When the ESP32 receives power, `main.cpp` triggers the following setup sequence:

1. **Network**: `brain` initialises the Wi-Fi Access Point (`192.168.4.1`) and opens WebSocket port `81`
2. **Hardware bus**: I²C bus initialises on GPIO 21 (SDA) and GPIO 22 (SCL)
3. **Peripherals**: OLED screen (`0x3C`) boots to the neutral face; PCA9685 (`0x40`) powers up
4. **Posture**: `nervous_system` commands all servos to their default standing angles defined in `config.h`

### Execution loop

FaceHugger runs on a non-blocking, continuous update loop:

1. `brain` listens for incoming WebSocket packets from the app
2. On receipt (e.g. `{"T":1,"dir":"FW"}`), it parses the JSON and updates the target state in the shared data structure
3. `nervous_system`'s FSM reads the state and calculates the next micro-step for the active gait
4. `face` checks whether the robot's state requires an emotional update (e.g. confused jittering when stopped or inverted) and pushes pixels to the OLED

### Finite State Machine (FSM)

The physical posture and gait cycle are driven by an FSM inside `SpinalCord`. There are six states (`data.h`):

| State | Value | Meaning |
|---|---|---|
| `STATE_IDLE` | 0 | Holding position, awaiting a command |
| `STATE_WALK` | 1 | Executing a gait |
| `STATE_ACTION` | 2 | Playing a one-shot clip (including the wall-flip, which is a clip) |
| `STATE_FAILSAFE` | 3 | Hardware exception or flipped; motion suppressed |
| `STATE_REST` | 4 | All servos at 90 degrees: the flat calibration pose, safe to power off |
| `STATE_STAND` | 5 | Standing on the per-leg `NEUTRAL[]` pose; the launch reference for gaits |

```mermaid
stateDiagram-v2
    [*] --> STATE_IDLE

    STATE_STAND --> STATE_WALK : Valid joystick input
    STATE_WALK --> STATE_STAND : Stop command (eases back to standing)

    STATE_IDLE --> STATE_STAND : Stand command
    STATE_IDLE --> STATE_REST : Relax command (flat calibration)
    STATE_REST --> STATE_STAND : Stand command

    STATE_IDLE --> STATE_ACTION : Play clip
    STATE_ACTION --> STATE_IDLE : Clip complete

    STATE_WALK --> STATE_FAILSAFE : Hardware exception / flipped
    STATE_FAILSAFE --> STATE_IDLE : Reset
```

A gait launches from `STATE_STAND` and, when stopped, eases back to standing rather than dropping to idle. `STATE_REST` is the all-90 calibration pose used when mounting servo horns or powering down, not a "neutral" pose.

## Setup

### PlatformIO: Firmware (ESP32)

**Prerequisites:** [VS Code](https://code.visualstudio.com/) with the [PlatformIO extension](https://platformio.org/install/ide?install=vscode) installed.

!!! warning
    The OLED bitmaps require significant flash memory. Skipping the partition step below will cause an overflow error at compile time.

**Steps:**

1. Clone the repository and open the firmware folder in VS Code
2. PlatformIO will automatically detect `platformio.ini` and install the required libraries
3. Confirm `platformio.ini` contains the following partition override:
```ini
    [platformio]
    default_envs = upesy_wroom

    [env:upesy_wroom]
    platform = espressif32
    board = upesy_wroom
    framework = arduino
    monitor_speed = 115200
    monitor_filters = direct, esp32_exception_decoder
    monitor_dtr = 0
    monitor_rts = 0
    lib_deps =
        pololu/VL53L0X @ ^1.3.1
        bblanchon/ArduinoJson @ ^7.0.0
        links2004/WebSockets @ ^2.4.1
        adafruit/Adafruit PWM Servo Driver Library
        adafruit/Adafruit GFX Library @ ^1.11.5
        adafruit/Adafruit SSD1306 @ ^2.5.7

    [env:native]
    platform = native
    test_framework = unity
    lib_deps = bblanchon/ArduinoJson @ ^7.0.0
    build_flags =
        -std=c++14
        -Isrc/nervous_system
        -Isrc/brain
        -D UNITY_INCLUDE_DOUBLE
    build_src_filter =
        +<nervous_system/kinematics.cpp>
        +<nervous_system/motion_math.cpp>
        +<brain/csv_log.cpp>
        +<brain/clip_list_serializer.cpp>
    test_build_src = yes
```

The `[env:native]` block builds a handful of source files on the host (no ESP32 needed) so the Unity tests can run, including the IK math and the math-to-servo transform shared with the simulation. Run them with `pio test -e native`.
4. Connect the ESP32 via USB, then run the following commands from the PlatformIO terminal:
```bash
   pio run                        # compile the firmware
   pio run -t upload              # flash to the ESP32
   pio device monitor -b 115200   # open the serial monitor to verify boot
```
5. A successful boot prints the ESP32's assigned IP address and confirms the WebSocket server is listening on port `81`

### React Native: Remote Control App

**Prerequisites:** [Node.js](https://nodejs.org/) (v18 or later) and the [Expo Go](https://expo.dev/go) app installed on your iOS or Android device.

**Steps:**

1. Navigate to the app directory:
```bash
   cd remote-control-app/MyApp
```
2. Install dependencies:
```bash
   npm install
```
3. Start the Expo development server:
```bash
   npx expo start
```
4. Scan the QR code displayed in the terminal with Expo Go (Android) or the default Camera app (iOS)
5. The app will load on your device. Before using it, ensure your phone is connected to the FaceHugger Wi-Fi hotspot (see [Running](#running) below)

## Running

### Power-on sequence

!!! danger "Order matters"
    Always follow this sequence exactly. Powering the servos before the ESP32 is
    fully booted will cause the PCA9685 to output undefined PWM signals, which can
    violently snap all 12 servos to random positions and damage the leg joints.

!!! warning "USB vs LiPo: never both at once"
    Do not connect the ESP32 to a PC via USB while the system is powered by the
    LiPo. Pick one power source: USB for development and flashing, LiPo for
    untethered operation. Running both simultaneously can damage the ESP32's
    onboard voltage regulator.

1. **Place the robot on a flat surface.** Ensure all four legs are extended and
   the robot is right-side up. The servos will snap to their default standing pose
   the moment power is applied.

2. **Choose your power source:**

    === "LiPo (untethered operation)"

        Connect the LiPo to the BMS. This simultaneously powers the ESP32 logic
        (via the Buck Converter) and the servo rail (via the PCA9685). Everything
        comes up at once, so the full sequence below applies.

    === "USB (development / debugging)"

        Plug the ESP32 in via USB. This powers the logic only, so the servos will
        not be energised. Use this mode when flashing firmware or reading serial
        logs. Do not connect the LiPo at the same time.

3. **Wait for the OLED face.** The neutral eye sprite appearing on screen
   confirms that the I²C bus is stable, the PCA9685 is initialised at `0x40`, and
   the WebSocket server is listening on port `81`. If the screen stays blank, check
   your I²C wiring on GPIO 21 (SDA) and GPIO 22 (SCL).

4. **Connect to the hotspot.** On your phone or laptop, open Wi-Fi settings and
   connect to the FaceHugger network. The ESP32 Access Point is statically assigned
   to `192.168.4.1`, so no DHCP configuration is required.

5. **Launch the app.** Open Expo Go and load the remote control app. The app will
   attempt to open a WebSocket connection to `ws://192.168.4.1:81`. A successful
   connection is indicated by the controller UI becoming active. If the connection
   times out, confirm your device is on the FaceHugger hotspot and not your home
   Wi-Fi.

6. **Test before moving.** Gently nudge each leg by hand to confirm all 12 servos
   are holding position with resistance. A loose or unresponsive leg indicates a
   disconnected servo cable or a wrong PCA9685 channel assignment in `config.h`.

### Shutdown sequence

Shutting down in the wrong order can leave the servos in an unpowered but
commanded state, causing the robot to collapse suddenly.

1. **Stop all motion.** Send a stop command from the app and wait for the robot
   to return to its standing pose
2. **Disconnect the LiPo.** Unplug the battery from the BMS. This simultaneously
   cuts power to the servos and the logic rail. The robot will go limp, so keep a
   hand under it or lay it on its side before pulling the connector
3. **Disconnect logic power.** If in USB development mode, unplug the USB cable
4. **Close the app**

### Host-side simulation

The PyBullet simulation lets you develop and test gaits and clips entirely offline,
without any risk to the hardware. By default it runs the **exact compiled firmware**
in the loop, so the motion you see is produced by the same C++ that runs on the robot.

**Prerequisites:** Python 3.12 and a few packages. On macOS there is no PyBullet wheel
on PyPI, so a **conda environment is the recommended setup** (it also pulls in the
pybind11 toolchain used to compile the firmware into the sim). One environment covers
the simulator and the helper scripts:

```bash
conda create -n facehugger python=3.12
conda activate facehugger
conda install -c conda-forge pybullet pybind11
pip install -r code/simulation/requirements.txt
```

On Linux you can skip conda and `pip install -r code/simulation/requirements.txt`
directly. See [Software environments](#software-environments) below for the full
picture of which folders need which environment.

**Common commands** (run from the repo root):

```bash
python code/facehugger.py sim                 # GUI, standing pose
python code/facehugger.py sim --walk          # walk gait (firmware in the loop)
python code/facehugger.py sim --trot          # trot gait
python code/facehugger.py sim --clip "wave"   # play a baked clip
python code/facehugger.py sim --serve         # firmware-backed WebSocket API on :8081
python code/facehugger.py sim --app           # sim + WebSocket API + the web app
```

`--walk` and `--trot` are separate gaits, both driven by the compiled firmware; pass
`--python` to use the pure-Python re-port instead (no C++ toolchain needed).
`sim --serve` runs the same `T:` WebSocket protocol as the real robot, so the mobile
app or the browser [control panel](../reference/remote-control/control-panel.md) can
drive the sim; `sim --app` brings up the sim, the API, and the web app together. The
full flag surface, the under-the-hood firmware-in-the-loop design, and the Blender and
`flash` subcommands are documented in the
[simulation CLI reference](../reference/simulation/cli.md).

!!! tip
    Validate any change to gait parameters or clips in the sim before flashing the
    ESP32. A gait that looks stable in simulation is not guaranteed stable on
    hardware, but a gait that fails in simulation will always fail on hardware.

## Software environments

Each toolchain manages its own dependencies; there is no single environment that
spans all of them, because they run in different runtimes.

- **Simulation (`code/simulation/`)** is the only host-Python project. Use one conda
  environment named `facehugger` (PyBullet and pybind11 from conda-forge, the rest
  from `requirements.txt`). The same env runs the simulator, the URDF generator, and
  the verification scripts.
- **Firmware (`code/firmware/`)** is managed entirely by PlatformIO, which creates
  its own isolated build environments from `platformio.ini`. No Python env is needed.
- **Mobile app (`code/remote-control-app/MyApp/`)** uses npm; `npm install` reads
  `package.json`.
- **Animation and CAD** run inside Blender and Fusion 360, each using that
  application's bundled Python. The scripts are loaded from within the app, not run
  against a project environment.

So "one environment for everything" is not possible across these runtimes, but the
host-Python side is genuinely one conda env. A `pyproject.toml` for `code/simulation/`
(with optional-dependency groups for sim, the WebSocket API, and docs) would be a
reasonable future tidy-up, but `requirements.txt` is what the project uses today.

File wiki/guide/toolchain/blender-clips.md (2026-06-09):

# Blender clip authoring and export

FaceHugger clips are one-shot authored gestures baked in Blender and exported as
C headers for firmware playback. The workflow requires Blender 5.0 or later. The
add-on uses the layered Action API introduced in Blender 4.4, and 3.3 LTS is no
longer supported.

## Prerequisites

- Blender 5.0+ installed (5.1 recommended).
- The rig file at `animation/fh_rigged_latest.blend` (git-lfs tracked). If it is
  absent, regenerate it with `python code/facehugger.py blender --rigged` from
  the repo root.
- `animation/convention.json` committed (neutral joint angles, scale factor,
  servo channel map).

## Opening the rig

Open `animation/fh_rigged_latest.blend` in Blender. The scene contains the
`FaceHuggerRig` armature (hidden by default) and five control objects:
`body_ctrl` and the four foot targets `foot_target_fl/fr/bl/br`. You author
clips by posing these controls, not the armature bones directly.

## Using the FH Clip Panel

Press `N` in the 3D Viewport to open the sidebar, then switch to the
**FaceHugger** tab. The panel provides:

- **Clips**: create, rename, duplicate, and overwrite named clip bundles. Each
  clip is a set of five Actions (one per control object). Switch the active clip
  by clicking its entry in the list.
- **Poses**: a commit-tracked library of control-object snapshots. Apply a pose
  to set the viewport without keyframing, then use **Key into Clip** to record
  the pose as a keyframe at the current frame.
- **Export**: bake and export the active clip (or the ticked selection) to CSV,
  C header (`.h`), and browser JavaScript (`.js`). The bundled
  `clips_all.h` + `clips_manifest.json` is the format consumed by the on-board
  clip player, and it is built from exactly the ticked clips, so the per-row
  checkboxes are how you choose which clips end up on the robot.

A **Preview Robot Motion** toggle switches F-curves between Bezier (authoring)
and Linear (exact robot playback) without losing Bezier handles.

## Headless export

To re-export all clips from the command line without opening the GUI, use:

```bash
BLENDER_BIN=/Applications/Blender-5.1.app/Contents/MacOS/Blender \
  "$BLENDER_BIN" --background --factory-startup \
  animation/fh_rigged_latest.blend \
  --python animation/addons/export_all_clips.py
```

The `--factory-startup` flag prevents conflicts from any user add-ons. Output
lands in `animation/exported_clips/`: per-clip folders and the bundled
`clips_all.h` and `clips_manifest.json` at the top level. Exit code 0 means all
clips exported cleanly.

## Getting the clip onto the robot

The bundled `clips_all.h` is a self-contained drop-in: the firmware compiles
`code/firmware/src/nervous_system/clips_all.h`, which is exactly the file the
exporter writes (no per-clip `#include` and no separate `.cpp` to edit). Getting a
clip onto the robot is therefore just keeping that file in sync and reflashing.

By default the panel does the sync for you: with the **Copy clips_all.h to
firmware** toggle on (in the Export sub-panel), every bundle export copies
`clips_all.h` straight into the firmware tree and reports the destination path. The
**Firmware** folder button opens that directory. If you turn the toggle off, or run
outside a repo checkout, copy `animation/exported_clips/clips_all.h` over
`code/firmware/src/nervous_system/clips_all.h` yourself.

Validate the exports before flashing:

```bash
python3 animation/scripts/check_export_consistency.py
```

This checks that every clip's `.h` and `.js` agree with the servo-frame convention
(exit code 0 means all pass). Then reflash with `pio run -t upload`. See
[Flashing the firmware](flashing.md). Because the simulator runs the same firmware,
the clip is then playable in the sim too.

For the full feature reference (pose library, selection sets, activity heatmap,
authoring-time warnings, and integration tests), see
[the Clip Panel reference](../../reference/animation/clip-panel.md).

Script warning — update your scripts

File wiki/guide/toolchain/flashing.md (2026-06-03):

# Flashing the firmware

The firmware is a PlatformIO project targeting the `upesy_wroom` ESP32 board.
Build, flash, and open the serial monitor with the three commands below. Run them
from the `code/firmware/` directory.

```bash
cd code/firmware
pio run -e upesy_wroom
pio run -t upload
pio device monitor
```

`pio device monitor` opens a 115200-baud serial console with the PlatformIO
exception decoder. Watch for FSM state transitions and any `[WARN] servo <ch>
clamped` lines during testing.

If `pio run -t upload` can't find the board, hold the BOOT button while it
starts flashing, or confirm you're using a data USB cable (charge-only cables
look the same and silently break the upload).

## Connecting to the robot

Once flashed, the ESP32 starts a Wi-Fi access point. Join it from your laptop or
phone before sending commands.

- Network: `FaceHugger_Net`
- Password: `12345678`
- WebSocket endpoint: `ws://192.168.4.1:81`

Commands are JSON objects sent over the WebSocket. For example, open a browser
console on a non-HTTPS page and run:

```js
const ws = new WebSocket("ws://192.168.4.1:81");
ws.send(JSON.stringify({ T: 2, s: 0 }));   // transition to IDLE
```

See the [API reference](../../reference/api.md) for the full command protocol.

## Quick bench test from a browser console

When you're sitting next to the robot and want to sanity-check a clip without
opening the mobile app, the browser console is the fastest path. Open one on
a plain non-HTTPS page (`about:blank` works) — `ws://` connections are blocked
from `https://` origins, which is the usual reason "nothing happens." Paste:

```js
const ws = new WebSocket("ws://192.168.4.1:81");
ws.onopen = () => ws.send(JSON.stringify({ T: 7, c: 4 }));  // play clip id 4
```

`T: 7` is the "play clip" command and `c` is the clip id. Ids come from
`animation/exported_clips/clips_manifest.json` (or `T:8` over the same socket).
The robot plays the clip once and then eases back to the neutral standing pose
over about half a second — that return-to-stand is the normal terminator for
every clip. Sending another `T:7` while a clip is still playing simply restarts
with the new one; sending a movement command (`T:5` to pick a gait, then
`T:1`) hands control back to the gait engine immediately.

What success looks like on the serial monitor: a single `[clip] play <name>
(<N> frames)` line, the motion completes, then idle. A flood of
`[WARN] servo <ch> clamped` lines means a clip is pushing a joint past its
range — re-tune the animation in Blender before flashing again.

To cross-check the on-robot playback against the browser-side ground truth,
paste the standalone `animation/exported_clips/<name>/<name>.js` into the same
console. It streams the exact same servo trace over the same socket without
the firmware's `T:7` decoder in the loop, so a divergence isolates the bug
to the firmware side.

## End-to-end: a Blender clip onto the running robot

A new authored clip reaches the robot in three stages: author and export in Blender, flash the firmware, then verify on device.

Author the clip and export it as described in [Blender clip authoring and export](blender-clips.md). With the **Copy clips_all.h to firmware** toggle on (the default), the FH Clip Panel writes the bundled `clips_all.h` straight into `code/firmware/src/nervous_system/clips_all.h` — there is no per-clip `#include` to add and no array to edit. Validate the bundle before flashing with `python3 animation/scripts/check_export_consistency.py` from the repo root; exit code `0` means every clip's `.h` agrees with its `.js` under the servo-frame convention.

Flash with `pio run -t upload` as above. Then join `FaceHugger_Net` and open the mobile app's **Actions** tab. The clip list is read from the firmware at runtime via `T:8`, so a freshly-flashed clip should appear without changes to the app. Tap it; the app sends `T:7` with the clip id, and the robot plays the motion. If a clip is missing, confirm it was ticked in the FH Clip Panel before export and watch the serial monitor for boot errors. If the motion is wrong, fix the animation, re-export, and reflash — the simulator runs the same firmware, so the same clip plays the same way in the sim.

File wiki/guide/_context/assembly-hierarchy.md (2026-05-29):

<!--
WIKI-MIGRATION REFERENCE COPY
Original path:  code/simulation/docs/ASSEMBLY_HIERARCHY.md
Original kind:  spec
Copied on:      2026-05-21
Status:         unreviewed
Maps to:        guide/parts/printed-parts.md
-->

> **Reference material.** Verbatim copy of `code/simulation/docs/ASSEMBLY_HIERARCHY.md` kept in `_context/`
> as source for the published wiki page. Edit the parent wiki page, not
> this file. The original at `code/simulation/docs/ASSEMBLY_HIERARCHY.md` is still canonical; this file is
> scaffolding the user will delete manually once the wiki pages exist.
<!--
CONSISTENCY-CHECK 2026-05-21
Verified against: feat/wiki-setup @ 0a1a138
- [ok]    Body-side landmarks LegMountPointFL/FR/BR/BL and joint origins BodyToLink1Point/Link1ToLink2Point/Link2ToLink3Point + LegMountFixedPoint all present in the exporter's CONSTRUCTION_POINTS (cad/scripts/ExportBodiesToURDF/.../ExportBodiesToURDF.py:114-135).
- [ok]    Link bodies match cad/leg/: Link1L, Link1R, Link2 (Link2L), Link3 (Link3L), LegMountL, LegMountR — and EXPORT_RULES references the same occurrences (Link1L:1/Link1R:1/Link2L:1/Link3L:1, MotorMount:1/MotorMountR:1). Joints Link1/2/3Revolute confirmed (_REQUIRED_JOINTS).
- [stale] Servo xrefs are out of date. Doc shows "Servo_Mouser_Model:1/2/3" with body "ServoBase". The exporter has 0 references to Servo_Mouser_Model; servos are now LegBaseServoEnclosure:N occurrences with a ServoMountPoint landmark (10 references). Replace Servo_Mouser_Model/ServoBase → LegBaseServoEnclosure/ServoMountPoint.
- [drift] Root node "FullBodyAssembly" is not used by the exporter — occurrence paths are rooted at FlexibleSkeleton:1/... and FaceHuggerLegAssembly:1/... (active-design root). Hierarchy is otherwise consistent.
- [drift] base mesh combine-rule: doc/QuadrupedBody:1 only; EXPORT_RULES combines QuadrupedBody:1 + LipoCage:1 into one base STL (ExportBodiesToURDF.py:204-215). cad/body/ also has BehindBridge.stl / MiddleBridge.stl not represented in this tree.
- [ok]    There's an extra construction point in the exporter not shown in the tree (BodyBottomPoint, Link3TipPoint) — additive, doesn't contradict the doc.
- [todo] (hidden) electronics components (PCB/PCA9685/Buck/OLED/vl53l0x/MPU6050/Lipo_Protector) and the VISIBLE_ONLY exclusion are CAD-state assertions not checkable from the exporter source alone.
-->
# FullBodyAssembly — Component Hierarchy

Notation:
  [asm]     = assembly component (has sub-components)
  [xref]    = external reference (linked file)
  [body]    = body inside a component
  (hidden)  = not visible, excluded by VISIBLE_ONLY=True

Only ServoBase body shown for servo xrefs (other servo bodies omitted for brevity).

---

[asm] FullBodyAssembly
│
├── [xref] FlexibleSkeleton:1
│   │
│   ├── Construction/
│   │   ├── LipoProtectorSketchPlane
│   │   ├── LegMountPointFL          ← body-side shoulder anchor, FL
│   │   ├── LegMountPointBL          ← body-side shoulder anchor, BL
│   │   ├── LegMountPointFR          ← body-side shoulder anchor, FR
│   │   └── LegMountPointBR          ← body-side shoulder anchor, BR
│   │
│   ├── [comp] QuadrupedBody:1
│   │   └── [body] QuadrupedBody
│   │
│   ├── [comp] PCB_ESP32-38Pins:1    (hidden)
│   ├── [comp] PCA9685 v18:1         (hidden)
│   ├── [comp] BuckConverter:1       (hidden)
│   ├── [comp] OLED 128x64 Display:1 (hidden)
│   ├── [comp] vl53l0x:1             (hidden)
│   ├── [comp] Lipo_Protector:1      (hidden)
│   ├── [comp] MPU6050 v2:1          (hidden)
│   ├── [comp] vl53l0x:2             (hidden)
│   │
│   └── [xref] LipoCage:1
│       └── [body] LipoCage
│
└── [xref] FaceHuggerLegAssembly:1
    │
    ├── Relationships/
    │   └── Joints/
    │       ├── Link3Revolute         ← revolute, Link2L→Link3L, axis=Link2ToLink3Axis
    │       ├── Link2Revolute         ← revolute, Link1L→Link2L, axis=Link1ToLink2Axis
    │       └── Link1Revolute         ← revolute, MotorMount→Link1L, axis=BodyToLink1Axis
    │
    ├── Construction/
    │   ├── Link1Alignment            (hidden)
    │   ├── Link2Alignment            (hidden)
    │   ├── Link3Alignment            (hidden)
    │   ├── BodyToLink1Axis           ← shoulder rotation axis
    │   ├── Link1ToLink2Axis          ← hip rotation axis
    │   ├── Link2ToLink3Axis          ← knee rotation axis
    │   ├── BodyToLink1Point          ← shoulder joint origin (world = LegMountPointXX)
    │   ├── Link1ToLink2Point         ← hip joint origin
    │   └── Link2ToLink3Point         ← knee joint origin
    │
    ├── [xref] Servo_Mouser_Model:1
    │   └── [body] ServoBase          (other servo bodies omitted)
    │
    ├── [xref] Servo_Mouser_Model:2
    │   └── [body] ServoBase
    │
    ├── [xref] Servo_Mouser_Model:3
    │   └── [body] ServoBase
    │
    ├── [comp] Link1L:1
    │   └── [body] Link1              ← L-side shoulder link
    │
    ├── [comp] Link2L:1
    │   └── [body] Link2              ← upper leg (shared, no R sibling yet)
    │
    ├── [comp] Link3L:1
    │   └── [body] Link3              ← lower leg (shared, no R sibling yet)
    │
    ├── [xref] MotorMount:1
    │   ├── [body] LegMountL          ← L-side bracket body
    │   ├── Construction/
    │   │   └── LegMountFixedPoint    ← bracket-side anchor (mates with LegMountPointXX)
    │   └── [xref] Servo_Mouser_Model:1
    │       └── [body] ServoBase
    │
    ├── [comp] Link1R:1
    │   └── [body] Link1R             ← R-side shoulder link (XZ mirror of Link1L)
    │
    └── [xref] MotorMountR:1
        ├── [body] LegMountR          ← R-side bracket body (XZ mirror of LegMountL)
        ├── Construction/
        │   └── LegMountFixedPoint    ← bracket-side anchor (same name as L side)
        └── [xref] Servo_Mouser_Model:1
            └── [body] ServoBase

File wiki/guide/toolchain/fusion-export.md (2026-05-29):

# Fusion 360 export scripts

Two Fusion 360 scripts live in `cad/scripts/`, both written for this project. They
run inside Fusion, not in the host Python environment, so you load them through
Fusion's own script runner. (Their manifests declare `type: script`, so they are
Scripts you run on demand, not persistent Add-Ins.)

To load either one: open Fusion 360, go to **Utilities -> ADD-INS -> Scripts and
Add-Ins**, stay on the **Scripts** tab, click the green `+` next to **My Scripts**,
and browse to the script's inner folder (the one containing the `.py` and
`.manifest`). It then appears in the list; select it and click **Run**. You only
need to add it once; afterwards it stays in **My Scripts**.

!!! todo "Add install screenshots"
    Add screenshots of the Scripts and Add-Ins dialog, the green `+`, and the
    folder picker, so a first-time user can follow along.

## ExportBodiesToURDF

Folder: `cad/scripts/ExportBodiesToURDF/`

This add-in is the first stage of the URDF pipeline. It reads the Fusion assembly
and writes three outputs to `code/simulation/generated/`:

- `fusion_export.json`: CAD tree, mesh manifest (`mesh_files`), per-occurrence
  world transforms, and the `_servo_role_assignment` field that maps meshes to
  firmware servo roles. Re-runs preserve any edits you have made to
  `_servo_role_assignment`.
- `fusion_export.txt`: human-readable version of the same tree, for quick
  inspection.
- `exported_meshes/*.stl`: eight STL files (chassis, leg mounts, shoulders,
  upper and lower links, servo). Each leg mesh is re-origined to its URDF joint
  landmark, so the URDF generator can emit `<origin xyz="0 0 0"/>` on visuals
  without offset adjustments.

After running the add-in, run `python code/facehugger.py urdf` from the repo root
to regenerate `facehugger.urdf` from the new export.

If the chassis STL contains unexpected electronics or PCBs, the `combined.parts`
list in the add-in source (`ExportBodiesToURDF.py`) is out of date; add or remove
the relevant occurrences and re-run.

## ExportPrintableSTLs

Folder: `cad/scripts/ExportPrintableSTLs/`

This add-in is independent of the URDF pipeline. It exports print-ready STLs with
a per-body up-axis rotation applied, suitable for slicing. Its output is not
consumed by `generate_urdf.py` or any other pipeline script.

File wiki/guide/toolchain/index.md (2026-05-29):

# Toolchain

FaceHugger's build pipeline connects four tools in a fixed order. Understanding
each stage prevents surprises when you change something upstream and wonder why
nothing moved downstream.

**Fusion 360 -> URDF export.** The two Fusion scripts in
`cad/scripts/ExportBodiesToURDF/` and `cad/scripts/ExportPrintableSTLs/` are the
first stage. The URDF exporter writes a JSON manifest and STL meshes that the
Python generator (`generate_urdf.py`) turns into `facehugger.urdf`. Everything
downstream is derived from that URDF, so never hand-edit the generated files. See
[Fusion 360 export scripts](fusion-export.md) for the step-by-step.

**URDF -> Blender rig.** Running `python code/facehugger.py blender --rigged`
ingests the URDF and builds an armature in Blender 5.x. The rigged scene
(`animation/fh_rigged_latest.blend`) is the starting point for clip authoring.

**Blender rig -> clip authoring and export.** The FH Clip Panel (N-panel add-on
in Blender) lets you pose the rig, record keyframe bundles, and export them as C
headers and JavaScript players that the firmware can play back. See
[Blender clip authoring and export](blender-clips.md) for the workflow.

**Exported clips -> firmware flash.** The final step compiles the PlatformIO
project (which embeds the exported clip headers) and flashes it to the ESP32 over
USB. After flashing, the robot joins its own Wi-Fi network and accepts commands
over WebSocket. See [Flashing the firmware](flashing.md) for the commands.

## Setup: installing each component

Each component has its own toolchain; there is no single installer. Install only
the ones you need. The [`facehugger.py` CLI](../../reference/simulation/cli.md)
prints the relevant command if it hits a missing dependency. For the deeper
"which environment runs what" picture, see [Software](../software.md#software-environments).

### Simulation + the `facehugger.py` CLI (Python)

The only host-Python project, one environment for everything Python. On macOS use
conda (pybullet has no PyPI wheel there); the `environment.yml` is a one-shot:

```bash
cd code/simulation
conda env create -f environment.yml
conda activate facehugger
```

Linux / CI can skip conda and `pip install -r code/simulation/requirements.txt`.
Dependencies: Python 3.12, `pybullet`, `pyyaml`, `matplotlib` (only for `--log`
plots), and for the firmware software-in-the-loop build `pybind11` + CMake >= 3.15
+ a C++17 compiler, plus `websockets` / `sse-starlette` / `uvicorn` for
`sim --serve` and its telemetry. Without the C++ toolchain, the sim still runs via
`--python` (the Python re-port).

### Remote-control app (Node / Expo)

Needed to run the app, including `sim --app` (which serves it on the web):

```bash
cd code/remote-control-app/MyApp
npm install
```

Dependencies: Node.js 18+ and npm; Expo Go on a phone for the mobile flow. See
[Remote control app](../remote_control_app.md).

### Firmware (PlatformIO)

```bash
pip install platformio        # or the VS Code PlatformIO extension
```

PlatformIO pulls the ESP32 toolchain and the `lib_deps` from `platformio.ini` on
first build. Flash with `python code/facehugger.py flash`. See
[Flashing the firmware](flashing.md).

### Animation (Blender) and CAD (Fusion 360)

Blender 5.0+ (5.1 recommended) for the rig and clip authoring; the FH Clip Panel
add-on ships in the repo. Fusion 360 (with the two export scripts in
`cad/scripts/`) for the CAD and the URDF/print exports. See
[Blender clip authoring](blender-clips.md) and
[Fusion 360 export scripts](fusion-export.md).

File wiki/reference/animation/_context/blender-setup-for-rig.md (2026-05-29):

<!--
WIKI-MIGRATION REFERENCE COPY
Original path:  doc/animation-pipeline/animation-library-pipeline-blender-setup-for-animation-rig.md
Original kind:  design
Copied on:      2026-05-21
Status:         unreviewed
Maps to:        reference/animation/blender-rig.md
-->

> **Reference material.** Verbatim copy of `doc/animation-pipeline/animation-library-pipeline-blender-setup-for-animation-rig.md` kept in `_context/`
> as source for the published wiki page. Edit the parent wiki page, not
> this file. The original at `doc/animation-pipeline/animation-library-pipeline-blender-setup-for-animation-rig.md` is still canonical; this file is
> scaffolding the user will delete manually once the wiki pages exist.
<!--
CONSISTENCY-CHECK 2026-05-21
Verified against: feat/wiki-setup @ 0a1a138
- [stale] The whole rig.blend + animations.blend split via Link + Library Override is NOT how the tooling works. fh_clip_panel.py manages clips as 5-Action bundles ON A SINGLE rig file (animation/fh_rigged_latest.blend), via the layered Action API + Fake User — no second linked file, no Library Override. See animation/scripts/README.md "fh_clip_panel.py".
- [drift] Object-name contract: the foot empties are `foot_target_{fl,fr,bl,br}` (README line 77) and the body object is `body_ctrl`, not `foot_empty_FL` etc. Clip Actions are named `base_anim__<target>` / `<clip>__<target>` (fh_rename_actions.py migration table), not bare "walk_forward".
- [stale] export_fhc.py (T4) does not exist. Export is fh_clip_panel.py's FH_OT_export_clip → _frame_to_servo → to_js / to_c_header / to_csv into animation/exported_gaits/. Per-action custom-prop metadata (period_ms/clip_class) is the unstarted .fhc design, not implemented.
- [ok]    Core premise holds: the rig is regenerated by urdf_to_blender_rigged.py and clip animation must survive regeneration; foot targets keyed in body-frame; Fake User keeps Actions alive. The mechanism differs (single-file layered Actions, not two-file linking).
- [todo]  Foot-XYZ body-frame .fhc storage this doc assumes is design-only; the implemented clips store joint-angle Actions, exported as pre-scaled servo angles (.js/clips_all.h), not foot XYZ.
-->
# Animation Library Pipeline — Blender + Fusion Model Iterations

## The Problem

The robot model lives in Fusion 360 and is still being iterated. A pipeline already
exists to export it: Fusion → URDF → `urdf_to_blender_rigged.py` → `rig.blend`. Every
time the model changes, this script regenerates `rig.blend` from scratch.

The challenge is: **how do you build up a library of animations (walk, trot, wave, etc.)
over time, without losing them every time the Fusion model gets updated and the rig is
regenerated?**

---

## The Blender Features That Solve This

### Actions

An **Action** in Blender is a named data-block that holds a set of keyframes. It is the
unit of animation. Each clip — `walk_forward`, `trot`, `wave_fl` — is one Action.

Actions are independent of the scene. You switch between them in the **Action Editor**
(a mode of the Dope Sheet). All actions stored in a `.blend` file are accessible from the
dropdown, regardless of which one is currently "active" on the rig.

Critically: **Actions have a Fake User flag** (the shield icon in the Action Editor). If
enabled, Blender will not garbage-collect the Action on save even if it is not currently
assigned to any object. This is essential for a library file — without it, any action you
aren't currently previewing will disappear on the next save.

### Linked Libraries

Blender can reference data-blocks from an external `.blend` file in two ways:

- **Link**: a live reference. When the source file changes, the referencing file sees the
  update on reload. The linked data is read-only by default.
- **Append**: a one-time copy. The data becomes local and editable, but no longer tracks
  the source.

For this pipeline, **Link** is the right choice for the rig. You want `animations.blend`
to automatically pick up geometry and position changes whenever `rig.blend` is
regenerated, without touching your actions.

### Library Overrides (Blender 3.x+, current in 5.1)

When you Link a collection or object from an external file, it arrives read-only. To
animate it, you apply a **Library Override**: right-click the linked collection in the
Outliner → *Library Override → Make*. This creates a local override layer on top of the
linked data. You can now keyframe the empties and armature locally while still receiving
structural updates from the source file.

Library Overrides replaced the older Proxy system and are the correct approach in
Blender 5.1.

---

## The Recommended File Layout

```
rig.blend              ← auto-generated by urdf_to_blender_rigged.py
                         thrown away and regenerated freely
                         contains: mesh objects, armature, foot empties

animations.blend       ← your actual work, never touched by any script
                         links rig.blend via Library Override
                         contains: all Actions with Fake User enabled
                         walk_forward, trot, wave_fl, stand, ...
```

**Workflow when the Fusion model changes:**

1. Re-run the Fusion → URDF → Blender pipeline. `rig.blend` is regenerated.
2. Open `animations.blend`. Blender reloads the linked library automatically.
3. Updated geometry and rig positions appear. Your Actions are untouched — they are
   local data-blocks in `animations.blend` and the regeneration never touches that file.
4. Review each clip to check visual validity (see below). Adjust keyframes if needed.

---

## When Animations Stay Valid After a Model Change

Your Actions key the **foot empty positions in body-frame coordinates**. This means an
animation is valid across a model change as long as the reachable workspace of the feet
has not changed significantly.

Changes that are **safe** for existing animations:

- Mesh geometry refinements (surface detail, fillets, chamfers) with no structural change
- STL file updates that don't move the joint axes or mounting points
- Visual-only changes (appearance, materials)

Changes that **may invalidate** existing animations:

- Leg segment lengths change → the IK workspace shifts; foot targets that were reachable
  may now be out of range, or the robot's actual posture will look different even if the
  numbers are the same
- Hip mounting positions move → every clip's neutral pose is now wrong
- Joint axis orientations change → coordinates rotate; all keyframed positions are in the
  wrong frame

In practice: small corrections to an already-functional design rarely break animations.
A major redesign of the leg geometry will require re-authoring clips. The file split
described above means re-authoring is contained to `animations.blend` and is not caused
by the tooling — it is an unavoidable consequence of the geometry change itself.

---

## What Must Stay Stable for the Pipeline to Work

The pipeline's robustness rests on **object name stability**. Actions store keyframe
data as FCurve channel paths, which reference object names (e.g. `foot_empty_FL`,
`foot_empty_FR`). If `urdf_to_blender_rigged.py` renames these objects between runs,
existing actions will silently stop animating anything.

Concretely:

- The foot empty names must be identical across every regeneration of `rig.blend`.
- The armature and bone names must be identical.
- The body reference object (used to convert world → body frame in the exporter) must
  keep the same name.

Add an assertion to `urdf_to_blender_rigged.py` that explicitly sets these names as
constants rather than deriving them from URDF link names, which may change. A one-line
comment marking these as "pipeline contract names — do not change" is enough.

---

## Exporting Animations Over Time

Your `export_fhc.py` script (T4 in the roadmap) already handles this. From inside
`animations.blend`, the full clip library is always available via:

```python
for action in bpy.data.actions:
    # action.name  →  "walk_forward", "trot", "wave_fl", etc.
    # assign to rig, bake with visual_keying=True,
    # read foot empty FCurves, write .fhc
```

Running the script once exports every action in the file. There is no manual
"select which clips to export" step — the library and the export are the same thing.

A natural addition as the library grows: store per-action metadata as custom properties
directly on the Action (e.g. `action["period_ms"] = 600`, `action["clip_class"] = "TROT"`).
The exporter reads these instead of hard-coding them. This keeps the Blender file as the
single source of truth for both the keyframe data and the clip parameters.

---

## Summary

| Concern | Solution |
|---|---|
| Rig regeneration destroying animations | Separate `rig.blend` (generated) from `animations.blend` (authored); link via Library Override |
| Actions surviving file reloads | Fake User flag on every Action in `animations.blend` |
| Keeping animations valid across iterations | Minor model changes are safe; significant leg geometry changes require re-authoring — this is expected |
| Object name drift breaking channel paths | Hardcode pipeline contract names in the rig generator script |
| Exporting all clips at once | `bpy.data.actions` loop in `export_fhc.py` |

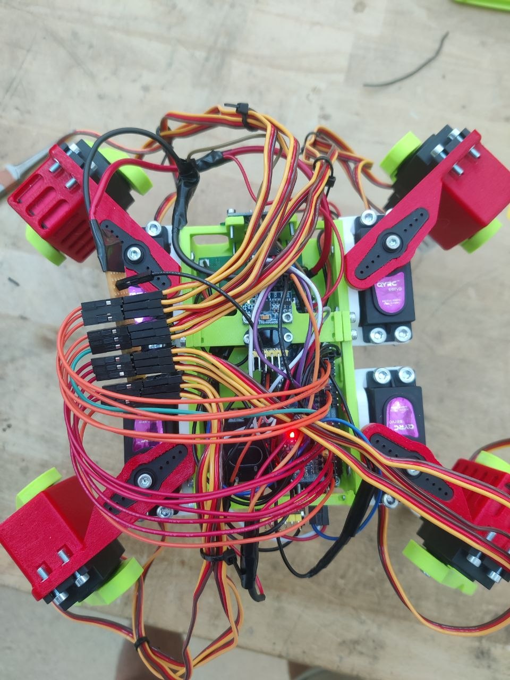
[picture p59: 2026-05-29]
wiki/assets/img/copper-board/full_setup.jpg

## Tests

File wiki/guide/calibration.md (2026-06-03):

# Calibration

Calibration ensures every servo's physical position matches what the firmware
believes it to be. Skipping this step will result in uneven standing poses,
asymmetric gaits, and joints that bind at the extremes of their range.

---

## How servos know their position

Servos do not have absolute encoders - they have no way of knowing where they
physically are when powered on. Instead, they respond blindly to PWM pulse widths:
a 1500µs pulse means "go to 90°", a 1000µs pulse means "go to 0°", and so on. The
firmware sends these pulses based on its own internal angle model, defined in
`config.h`.

This means that if a servo horn is pressed onto the spline slightly off-centre
(which is almost inevitable during assembly, since the spline has discrete teeth),
the physical angle and the firmware's assumed angle will be misaligned by one or
more teeth. The robot will stand and walk asymmetrically as a result.

The solution is to **separate the horn from the servo**, command the servo to its
reference position electronically, and only then press the horn back on at the
correct physical angle. This way the firmware's model and reality are guaranteed
to match.

---

## Procedure

!!! warning "Before you start"
    The robot must be fully assembled and powered. Follow the full power-on
    sequence in [Running](software.md#power-on-sequence) before proceeding.
    You will need a small Phillips-head screwdriver.

### Step 1: Remove all servo horns

With the robot powered and standing, unscrew the centre screw from each of the
12 servo horns. Once the screw is out, gently pull the horn straight off the
spline (it may be tight; wiggle it slightly if needed). Do not use a lever or
excessive force, as the spline teeth are delicate.

!!! tip
    Keep the 12 screws somewhere safe - a small cup or tray works well. They are
    easy to lose.

After this step all 12 servo shafts will be exposed with no horns attached.

### Step 2: Command the reference pose

In the remote control app, navigate to the **Actions** tab and press
**Reset Pose**. The firmware will send a 1500µs pulse (90°) to all 12 servos
simultaneously. You will hear the servos spin briefly to find their reference
position and then hold.

This is the intended behaviour: the servos spinning freely with no horns
attached is exactly what allows the calibration to work correctly.

### Step 3: Realign and reattach the horns

With all servos holding their electronic 90° reference, physically reattach each
horn at the correct mechanical angle before screwing it back down.

The target geometry is:

- **Hip joints:** when viewed from above, each hip should be angled at **45°
  relative to the horizontal plane**, pointing diagonally outward from the body
  corners
- **Thigh and knee joints:** the legs should lie **completely flat on the
  table**, fully extended, with no joint bent upward or downward

Correct calibration pose: top view showing 45° hip angles and flat legs

Press each horn onto its spline at the closest tooth position that achieves the
target angle, then drive the centre screw back in finger-tight before giving it a
final quarter turn.

!!! warning "Choose the closest tooth, not the perfect angle"
    The spline has a fixed number of teeth, so you may not be able to hit exactly
    45° or exactly flat. Choose the tooth position that gets closest and accept a
    small residual offset - this can be trimmed later in `config.h` by adjusting
    the default angle for that specific servo channel.

### Step 4: Verify

Once all 12 horns are reattached, press **Reset Pose** in the app a second time.
The robot should rise into a clean, symmetric standing pose with:

- All four legs extended flat
- The body level and centred
- No joint visibly cocked or twisted relative to its neighbours

If one leg looks obviously wrong, that servo's horn is likely off by one spline
tooth. Unscrew that horn, rotate it by one tooth in the required direction, and
repeat.

---

## Fine-tuning in `config.h`

A spline tooth is a few degrees wide, so after the horn step every thigh and
knee will still be a degree or two off mechanical flat. Rather than chasing
that out of the horn, the firmware lets you record where flat actually landed
and works from there. The eight `CALIB_*` macros at the top of
`code/firmware/src/shared/config.h` hold the **servo angle at which each thigh
or knee link is mechanically flat** (thigh horizontal, knee fully extended):

```cpp
#define CALIB_FR_THIGH  84
#define CALIB_FR_KNEE   95
#define CALIB_FL_THIGH  87
#define CALIB_FL_KNEE   82
#define CALIB_BR_THIGH 103
#define CALIB_BR_KNEE   80
#define CALIB_BL_THIGH  84
#define CALIB_BL_KNEE   87
```

The inverse-kinematics path (`translateToServo`) adds and subtracts deltas
**from these values**, not from a hardcoded 90, so the same math-space pose
produces the same physical pose on every leg regardless of which tooth the
horn ended up on. The upside-down pitch mirror (`applyInvert`) also pivots
around `CALIB`, not 90: it computes `2 * CALIB - angle` per joint, so an
inverted robot lands on the same physical flat as upright. Set all eight to
`90` to disable per-servo calibration and fall back to the pre-calibration
behaviour.

### Workflow

1. Stand the robot and open the app's **Individual Servo Control** for one
   thigh or knee. Drive the joint until the link is visually flat (thigh
   horizontal, or knee fully extended in line with the thigh).
2. Read the servo angle the app is sending in that pose.
3. Write that number into the matching `CALIB_<LEG>_<JOINT>` macro in
   `shared/config.h`.
4. Repeat for the other seven thigh/knee channels.
5. Rebuild and reflash. The `_DEFAULT_ANGLE` constants below the `CALIB`
   block are pre-computed `CALIB ± NEUTRAL` values and should be recomputed
   in the comments to match; a host-side parity test (`test_neutral_consistency`)
   catches a mismatch.

Hips are not calibrated this way. The hip target is a 45 deg outward angle,
not "flat", and trimming it is rarely useful past the one-tooth step above.

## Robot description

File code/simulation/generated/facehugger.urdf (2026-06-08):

<?xml version="1.0" ?>
<robot name="facehugger">

  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
  <link name="base_link">
    <inertial>
      <origin xyz="0.000319 0.002511 0.017386" rpy="0 0 0"/>
      <mass value="1.170749"/>
      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
    </inertial>
    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
  </link>

  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
  <joint name="fl_link1_joint" type="revolute">
    <parent link="base_link"/>
    <child link="fl_link1"/>
    <origin xyz="-0.050401 0.043222 0.036844" rpy="0 0 -0.785398"/>
    <axis xyz="0.0 0.0 1.0"/>
    <limit lower="-0.907571" upper="1.570796" effort="2.94" velocity="5.0"/>
  </joint>
  <joint name="fl_link2_joint" type="revolute">
    <parent link="fl_link1"/>
    <child link="fl_link2"/>
    <origin xyz="-0.046920 0.022395 -0.031598" rpy="0 0 0.0"/>
    <axis xyz="0.0 1.0 0.0"/>
    <limit lower="-1.308997" upper="1.308997" effort="2.94" velocity="5.0"/>
  </joint>
  <joint name="fl_link3_joint" type="revolute">
    <parent link="fl_link2"/>
    <child link="fl_link3"/>
    <origin xyz="-0.074700 0.000205 0.000000" rpy="0 0 0.0"/>
    <axis xyz="0.0 1.0 0.0"/>
    <limit lower="-1.570796" upper="1.570796" effort="2.94" velocity="5.0"/>
  </joint>
  <link name="fl_link1">
    <inertial>
      <origin xyz="0.042705 -0.015218 -0.030496" rpy="0 0 0"/>
      <mass value="0.192968"/>
      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
    </inertial>
    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
  </link>
  <link name="fl_link2">
    <inertial>
      <origin xyz="0.117869 0.018736 0.005004" rpy="0 0 0"/>
      <mass value="0.149366"/>
      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
    </inertial>
    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
  </link>
  <link name="fl_link3">
    <inertial>
      <origin xyz="0.177798 0.035157 0.001715" rpy="0 0 0"/>
      <mass value="0.187150"/>
      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
    </inertial>
    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
  </link>

  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
  <joint name="br_link1_joint" type="revolute">
    <parent link="base_link"/>
    <child link="br_link1"/>
    <origin xyz="0.050401 -0.043222 0.036844" rpy="0 0 2.356194"/>
    <axis xyz="0.0 0.0 1.0"/>
    <limit lower="-1.570796" upper="0.907571" effort="2.94" velocity="5.0"/>
  </joint>
  <joint name="br_link2_joint" type="revolute">
    <parent link="br_link1"/>
    <child link="br_link2"/>
    <origin xyz="-0.046920 0.022395 -0.031598" rpy="0 0 0.0"/>
    <axis xyz="0.0 1.0 0.0"/>
    <limit lower="-1.308997" upper="1.308997" effort="2.94" velocity="5.0"/>
  </joint>
  <joint name="br_link3_joint" type="revolute">
    <parent link="br_link2"/>
    <child link="br_link3"/>
    <origin xyz="-0.074700 0.000205 0.000000" rpy="0 0 0.0"/>
    <axis xyz="0.0 1.0 0.0"/>
    <limit lower="-1.570796" upper="1.570796" effort="2.94" velocity="5.0"/>
  </joint>
  <link name="br_link1">
    <inertial>
      <origin xyz="0.042705 -0.015218 -0.030496" rpy="0 0 0"/>
      <mass value="0.192968"/>
      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
    </inertial>
    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
  </link>
  <link name="br_link2">
    <inertial>
      <origin xyz="0.117869 0.018736 0.005004" rpy="0 0 0"/>
      <mass value="0.149366"/>
      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
    </inertial>
    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
  </link>
  <link name="br_link3">
    <inertial>
      <origin xyz="0.177798 0.035157 0.001715" rpy="0 0 0"/>
      <mass value="0.187150"/>
      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
    </inertial>
    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
  </link>

  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
  <joint name="fr_link1_joint" type="revolute">
    <parent link="base_link"/>
    <child link="fr_link1"/>
    <origin xyz="0.050401 0.043222 0.036844" rpy="0 0 0.785398"/>
    <axis xyz="0.0 0.0 1.0"/>
    <limit lower="-1.570796" upper="0.907571" effort="2.94" velocity="5.0"/>
  </joint>
  <joint name="fr_link2_joint" type="revolute">
    <parent link="fr_link1"/>
    <child link="fr_link2"/>
    <origin xyz="0.046920 0.022395 -0.031598" rpy="0 0 0.0"/>
    <axis xyz="0.0 -1.0 0.0"/>
    <limit lower="-1.308997" upper="1.308997" effort="2.94" velocity="5.0"/>
  </joint>
  <joint name="fr_link3_joint" type="revolute">
    <parent link="fr_link2"/>
    <child link="fr_link3"/>
    <origin xyz="0.074700 0.000205 0.000000" rpy="0 0 0.0"/>
    <axis xyz="0.0 -1.0 0.0"/>
    <limit lower="-1.570796" upper="1.570796" effort="2.94" velocity="5.0"/>
  </joint>
  <link name="fr_link1">
    <inertial>
      <origin xyz="0.070197 -0.059946 -0.028938" rpy="0 0 0"/>
      <mass value="0.209876"/>
      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
    </inertial>
    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
  </link>
  <link name="fr_link2">
    <inertial>
      <origin xyz="-0.117869 0.018736 -0.005004" rpy="0 0 0"/>
      <mass value="0.149366"/>
      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
    </inertial>
    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
  </link>
  <link name="fr_link3">
    <inertial>
      <origin xyz="-0.177798 0.035157 -0.001715" rpy="0 0 0"/>
      <mass value="0.187150"/>
      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
    </inertial>
    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
  </link>

  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
  <joint name="bl_link1_joint" type="revolute">
    <parent link="base_link"/>
    <child link="bl_link1"/>
    <origin xyz="-0.050401 -0.043222 0.036844" rpy="0 0 -2.356194"/>
    <axis xyz="0.0 0.0 1.0"/>
    <limit lower="-0.907571" upper="1.570796" effort="2.94" velocity="5.0"/>
  </joint>
  <joint name="bl_link2_joint" type="revolute">
    <parent link="bl_link1"/>
    <child link="bl_link2"/>
    <origin xyz="0.046920 0.022395 -0.031598" rpy="0 0 0.0"/>
    <axis xyz="0.0 -1.0 0.0"/>
    <limit lower="-1.308997" upper="1.308997" effort="2.94" velocity="5.0"/>
  </joint>
  <joint name="bl_link3_joint" type="revolute">
    <parent link="bl_link2"/>
    <child link="bl_link3"/>
    <origin xyz="0.074700 0.000205 0.000000" rpy="0 0 0.0"/>
    <axis xyz="0.0 -1.0 0.0"/>
    <limit lower="-1.570796" upper="1.570796" effort="2.94" velocity="5.0"/>
  </joint>
  <link name="bl_link1">
    <inertial>
      <origin xyz="0.070197 -0.059946 -0.028938" rpy="0 0 0"/>
      <mass value="0.209876"/>
      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
    </inertial>
    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
  </link>
  <link name="bl_link2">
    <inertial>
      <origin xyz="-0.117869 0.018736 -0.005004" rpy="0 0 0"/>
      <mass value="0.149366"/>
      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
    </inertial>
    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
  </link>
  <link name="bl_link3">
    <inertial>
      <origin xyz="-0.177798 0.035157 -0.001715" rpy="0 0 0"/>
      <mass value="0.187150"/>
      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
    </inertial>
    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
  </link>
</robot>

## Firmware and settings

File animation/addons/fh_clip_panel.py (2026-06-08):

# === Blender-only ===
# Installed via Edit > Preferences > Add-ons (or reloaded in place by
# the FH_OT_reload_panel operator).
"""
fh_clip_panel.py — FaceHugger clip manager (Blender 5.1.1)

Adds an "FH Clips" panel to the 3D viewport sidebar (N-panel,
category "FaceHugger"). Manages "clips" — named groups of 5 Actions
following the convention:

    <clip_name>__body_ctrl
    <clip_name>__foot_target_fl
    <clip_name>__foot_target_fr
    <clip_name>__foot_target_bl
    <clip_name>__foot_target_br

Each clip's Actions are assigned to their target objects using
Blender 4.4+'s layered Action API (action + action_slot), not via
the legacy single-action slot.

------------------------------------------------------------------
Loading into Blender
------------------------------------------------------------------

Option A — Install as add-on (persists across sessions):
  1. Edit > Preferences > Add-ons > Install...
  2. Pick this file, install, then tick "FH Clip Panel" to enable.
  3. Open the 3D viewport, press N, switch to the "FaceHugger" tab.

Option B — Run from the Text Editor (one-shot, for development):
  1. Open this file in Blender's Text Editor.
  2. Press Alt+P (or click "Run Script").
  3. The panel appears in the N-sidebar immediately. Re-running
     after edits unregisters the previous classes first, so you
     can iterate without restarting Blender.

Works on the existing animation/fh_rigged_latest.blend out of the
box — it just needs the rig objects body_ctrl / foot_target_<leg>
to exist in the scene.
"""

bl_info = {
    "name": "FH Clip Panel",
    "author": "FaceHugger team",
    "version": (0, 2, 0),
    "blender": (4, 4, 0),
    "location": "View3D > Sidebar > FaceHugger",
    "description": "Manage FaceHugger animation clips (body_ctrl + 4 foot_targets) using the layered Action API.",
    "category": "Animation",
}

import csv
import datetime
import importlib
import json
import math
import os
import sys
from pathlib import Path

import bpy

_LIB = str(Path(__file__).resolve().parents[1] / "lib")
if _LIB not in sys.path:
    sys.path.insert(0, _LIB)
# Firmware-parity Python re-port (CALIB + _frame_to_servo live here now,
# not in servo_math; the Blender panel imports them for its servo-space
# "current angles" preview, but the on-wire exporter paths stay math-space).
_FW_PORT_PARENT = str(Path(__file__).resolve().parents[2] / "code" / "simulation")
if _FW_PORT_PARENT not in sys.path:
    sys.path.insert(0, _FW_PORT_PARENT)

from servo_math import (  # noqa: E402
    _LEGS,
    _link1_delta_to_absolute,
    _scale_from_neutral,
)
from animation_tools.exporter_parity import _frame_to_servo  # noqa: E402

CATEGORY = "FaceHugger"
CLIP_TARGETS = [
    "body_ctrl",
    "foot_target_fl",
    "foot_target_fr",
    "foot_target_bl",
    "foot_target_br",
]
ANCHOR = "body_ctrl"

# Armature object that owns the 12 joint pose bones.
# body_ctrl is a cube Empty used for clip assignment; the real armature is FaceHuggerRig.
_ARM_OBJ_NAME = "FaceHuggerRig"

# Revolute-joint bones in export/heatmap order.
JOINT_BONES = [
    "fl_link1",
    "fl_link2",
    "fl_link3",
    "fr_link1",
    "fr_link2",
    "fr_link3",
    "bl_link1",
    "bl_link2",
    "bl_link3",
    "br_link1",
    "br_link2",
    "br_link3",
]

# Every joint's rotation axis is bone-local Z (euler index 2), uniformly
# across all 12 bones. The rig builder calls EditBone.align_roll(joint_axis)
# so bone-local Z == the URDF joint axis for ALL joints, including the
# per-side ± sign — see urdf_to_blender_rigged.py and
# the Blender-rig reference at wiki/reference/animation/blender-rig.md
# ("No per-joint axis branching anywhere", "rotation_euler[2] == joint
# angle"). The URDF axis
# being Y for link2/link3 is the *URDF-frame* axis, NOT the Blender
# bone-local axis: do not branch per-bone here. (A prior per-bone
# {link2/3: Y} map was wrong and silently exported zeros.)
_JOINT_AXIS_EULER_IDX = 2  # bone-local Z, all 12 bones

# Simultaneous-servo warning: flag frames where more than N servos move
# by more than this threshold in a single frame step.
_DELTA_THRESHOLD_DEG = 5.0

# Authoring-time torque guard: warn if any joint moves more than this many
# degrees between consecutive baked frames (fast keyframe = mechanical shock
# on hardware). Tunable; not a hard limit — the firmware clamp is the
# electrical backstop, this catches bad animation before it ships.
FRAME_DELTA_WARN_DEG = 20.0

# Recommended max authoring fps for robot export. Higher = more WS packets
# per second with no motion benefit for these slow clips. Not enforced —
# the animator sets fps in Output Properties; we only nudge.
RECOMMENDED_MAX_FPS = 12

# Heatmap colour thresholds (degrees).
_HEATMAP_MID_DEG = 5.0
_HEATMAP_HIGH_DEG = 20.0

# The heatmap colours the per-joint *servo* meshes. Only link1 (shoulder)
# and link3 (knee) export a discrete `<bone>__servo` mesh; link2 (the hip)
# has NO servo mesh — that servo was merged into a parent body during the
# CAD→URDF "combine parts" step. Consequence: the hip's activity is NOT
# visualised (8 of 12 joints are shown). This target was chosen
# deliberately over the joint bones (hidden armature) / leg-segment meshes.
_SERVO_MESH_FMT = "{bone}__servo"
_HEATMAP_NEUTRAL_COLOR = (1.0, 1.0, 1.0, 1.0)

# Module-level state for the heatmap handler / lossless toggle-off.
_heatmap_prev_angles: dict = {}
_heatmap_saved_obj_color: dict = {}  # mesh name -> prior obj.color tuple
_heatmap_saved_shading: list = []  # [(View3DShading, prior color_type)]
_heatmap_hip_gap_warned = False


def _warn_frame_deltas(rows):
    """Print a console WARNING for each joint that moves more than
    FRAME_DELTA_WARN_DEG between consecutive frames. Returns the number of
    warnings emitted (for tests)."""
    n = 0
    for prev, cur in zip(rows, rows[1:]):
        for bone in JOINT_BONES:
            delta = abs(cur[bone] - prev[bone])
            if delta > FRAME_DELTA_WARN_DEG:
                print(
                    f"WARNING: {bone} moves {delta:.0f}° between frame "
                    f"{prev['frame']} and {cur['frame']} "
                    f"(threshold: {FRAME_DELTA_WARN_DEG:.0f}°)"
                )
                n += 1
    return n


# ---------------------------------------------------------------------------
# Shared helpers
# ---------------------------------------------------------------------------


def _find_arm_obj():
    """Return the FaceHuggerRig armature object, or None."""
    return bpy.data.objects.get(_ARM_OBJ_NAME)


def _read_bone_angles(arm_eval):
    """Read the revolute-joint angle (deg) for each bone in JOINT_BONES
    from an already-evaluated armature object.

    The IK / Damped-Track / Limit-Rotation constraint stack writes the
    solved pose into each pose bone's evaluated ``matrix`` (pose/armature
    space) — NOT into ``rotation_euler`` or ``matrix_basis``, which keep
    their pre-constraint keyed values (identity for the IK-driven hip/knee
    bones). Reading ``rotation_euler`` therefore returns 0 for every
    IK-driven joint, which is why the first export wrote all-zero CSVs.

    Instead recover the *effective* basis: the ``matrix_basis`` the bone
    would hold if its evaluated pose had been keyed directly rather than
    constraint-solved. ``Bone.convert_local_to_pose(..., invert=True)`` is
    Blender's official inverse of pose composition (it accounts for
    inherit-scale / local-location). The joint angle is that basis'
    bone-local Z rotation, uniform across all 12 joints because the rig
    roll-aligns every joint axis onto bone-local Z (see
    ``_JOINT_AXIS_EULER_IDX``). For an FK-keyed bone this reduces exactly
    to its keyed ``rotation_euler[2]``, so FK shoulders are unaffected."""
    angles = {}
    for name in JOINT_BONES:
        pbone = arm_eval.pose.bones.get(name)
        if pbone is None:
            angles[name] = 0.0
            continue
        if pbone.parent is not None:
            basis = pbone.bone.convert_local_to_pose(
                pbone.matrix,
                pbone.bone.matrix_local,
                parent_matrix=pbone.parent.matrix,
                parent_matrix_local=pbone.parent.bone.matrix_local,
                invert=True,
            )
        else:
            basis = pbone.bone.convert_local_to_pose(
                pbone.matrix,
                pbone.bone.matrix_local,
                invert=True,
            )
        angles[name] = math.degrees(basis.to_euler("XYZ")[_JOINT_AXIS_EULER_IDX])
    return angles


def _servo_meshes():
    """{bone_name: servo mesh object} for the joints that have a servo
    mesh. link2 (hip) is intentionally absent — it has no `__servo` mesh."""
    out = {}
    for name in JOINT_BONES:
        obj = bpy.data.objects.get(_SERVO_MESH_FMT.format(bone=name))
        if obj is not None:
            out[name] = obj
    return out


def _set_servo_color(obj, rgb):
    """Apply an RGB tuple to a mesh object's viewport display colour."""
    obj.color = (rgb[0], rgb[1], rgb[2], 1.0)


def _iter_view3d_shadings():
    """Yield every View3D space's shading block (none in --background)."""
    for wm in bpy.data.window_managers:
        for win in wm.windows:
            screen = win.screen
            if screen is None:
                continue
            for area in screen.areas:
                if area.type != "VIEW_3D":
                    continue
                for space in area.spaces:
                    if space.type == "VIEW_3D":
                        yield space.shading


def _delta_to_rgb(delta_deg):
    """Map an angle delta to an RGB colour: green → orange → red."""
    if delta_deg < _HEATMAP_MID_DEG:
        return (0.10, 0.80, 0.10)
    if delta_deg < _HEATMAP_HIGH_DEG:
        t = (delta_deg - _HEATMAP_MID_DEG) / (_HEATMAP_HIGH_DEG - _HEATMAP_MID_DEG)
        return (0.10 + 0.80 * t, 0.80 - 0.65 * t, 0.10)
    return (0.90, 0.15, 0.05)


def _enter_servo_heatmap():
    """Snapshot prior servo colours + View3D solid-shading colour mode,
    then switch viewports to per-Object colour so obj.color shows."""
    _heatmap_saved_obj_color.clear()
    for name, obj in _servo_meshes().items():
        _heatmap_saved_obj_color[obj.name] = tuple(obj.color)
    _heatmap_saved_shading.clear()
    for shading in _iter_view3d_shadings():
        _heatmap_saved_shading.append((shading, shading.color_type))
        shading.color_type = "OBJECT"


def _reset_servo_heatmap():
    """Lossless toggle-off: restore servo colours and the prior
    View3D shading colour mode captured by _enter_servo_heatmap."""
    for name, prev in _heatmap_saved_obj_color.items():
        obj = bpy.data.objects.get(name)
        if obj is not None:
            obj.color = prev
    _heatmap_saved_obj_color.clear()
    for shading, prev in _heatmap_saved_shading:
        try:
            shading.color_type = prev
        except (ReferenceError, AttributeError):
            pass  # space/area was closed while the heatmap was active
    _heatmap_saved_shading.clear()


# ---------------------------------------------------------------------------
# Heatmap frame-change handler
# ---------------------------------------------------------------------------


def _heatmap_handler(scene, depsgraph):
    arm_obj = _find_arm_obj()
    if arm_obj is None:
        return
    arm_eval = arm_obj.evaluated_get(depsgraph)
    current = _read_bone_angles(arm_eval)
    servos = _servo_meshes()
    for name, angle in current.items():
        mesh = servos.get(name)  # link2 (hip) has no servo mesh -> skipped
        if mesh is None:
            continue
        delta = abs(angle - _heatmap_prev_angles.get(name, angle))
        _set_servo_color(mesh, _delta_to_rgb(delta))
    _heatmap_prev_angles.update(current)


def _toggle_heatmap(self, context):
    """BoolProperty update callback — registers or removes _heatmap_handler
    and manages the servo-mesh colouring lifecycle."""
    global _heatmap_hip_gap_warned
    handlers = bpy.app.handlers.frame_change_post
    if self.fh_heatmap_active:
        _enter_servo_heatmap()
        if _heatmap_handler not in handlers:
            handlers.append(_heatmap_handler)
        if not _heatmap_hip_gap_warned:
            _heatmap_hip_gap_warned = True
            hip = [b for b in JOINT_BONES if b.endswith("_link2")]
            print(
                "[fh_clip_panel] Activity Heatmap: link2/hip joints "
                f"({', '.join(hip)}) have no `__servo` mesh and are NOT "
                "shown — only the 8 shoulder/knee servos are coloured."
            )
    else:
        if _heatmap_handler in handlers:
            handlers.remove(_heatmap_handler)
        _reset_servo_heatmap()
        _heatmap_prev_angles.clear()


# ---------------------------------------------------------------------------
# Clip model
# ---------------------------------------------------------------------------


def _action_clip_name(action_name):
    """Strip a `__<target>` suffix from an Action name to recover the
    clip prefix. Returns None for anything that doesn't look like a
    well-formed clip action — including the cascading-suffix case
    (e.g. an orphan Action literally named "__foot_target_fl__foot_target_fl"
    that would otherwise leak the would-be prefix "__foot_target_fl"
    into list_clips() and the export UI). Legitimate clip names don't
    start with "__"."""
    for target in CLIP_TARGETS:
        suffix = f"__{target}"
        if action_name.endswith(suffix):
            clip = action_name[: -len(suffix)]
            if not clip or clip.startswith("__"):
                return None  # malformed / phantom
            return clip
    return None


def list_clips():
    names = set()
    for action in bpy.data.actions:
        clip = _action_clip_name(action.name)
        if clip:
            names.add(clip)
    return sorted(names)


def clip_action(clip, target):
    return bpy.data.actions.get(f"{clip}__{target}")


def active_clip():
    """The clip whose body_ctrl Action is currently assigned, or None."""
    obj = bpy.data.objects.get(ANCHOR)
    if obj is None or obj.animation_data is None or obj.animation_data.action is None:
        return None
    return _action_clip_name(obj.animation_data.action.name)


def _keep_action(action):
    """Mark a clip Action with the fake-user flag so it survives
    Blender's orphan-purge-on-save when it's not the currently-bound
    one. The user model is "all my clips persist regardless of which
    one is active" — without this, every non-active clip has zero
    users and gets garbage-collected on the next .blend save."""
    if action is not None:
        action.use_fake_user = True
    return action


def _rescue_existing_clip_actions():
    """Sweep bpy.data.actions on register, mark every clip-pattern
    Action (`<clip>__<target>`) as fake_user=True. Rescues clips that
    are still in the current .blend but were created before this fix —
    without the sweep they'd be lost on the very next save."""
    rescued = 0
    for action in bpy.data.actions:
        if _action_clip_name(action.name) is None:
            continue
        if not action.use_fake_user:
            action.use_fake_user = True
            rescued += 1
    return rescued


@bpy.app.handlers.persistent
def _on_save_pre(*_args, **_kwargs):
    """Re-sweep clip-pattern actions for fake_user RIGHT BEFORE Blender
    serialises to disk. This is the final guard against the inactive-
    clip-vanishes bug: even if some other code path (rig rebuild's
    restore_actions, a misbehaving extension, a fresh-Action creation
    site that bypasses `_keep_action`) clears use_fake_user mid-session,
    save_pre flips it back on the way to disk. Persistent so the
    handler survives .blend loads."""
    n = _rescue_existing_clip_actions()
    if n:
        print(
            f"[fh_clip_panel] save_pre: re-set fake_user on {n} clip"
            f" Action(s) to prevent orphan-purge during save"
        )


@bpy.app.handlers.persistent
def _on_load_post(*_args, **_kwargs):
    """Re-sweep clip-pattern actions after every .blend load — covers
    the case where the user opens a second file in the same Blender
    session (register() only runs once per addon lifetime, so the
    register-time sweep wouldn't fire). Persistent so the handler
    survives .blend loads."""
    n = _rescue_existing_clip_actions()
    if n:
        print(f"[fh_clip_panel] load_post: re-set fake_user on {n} clip Action(s)")


def assign_clip(clip):
    """Wire each of the 5 Actions onto its target object via the layered API.

    Returns (assigned_count, list_of_missing_strs). Missing entries are
    either 'object:<name>' (rig target absent) or 'action:<full_action_name>'
    (clip incomplete).
    """
    missing = []
    assigned = 0
    for target in CLIP_TARGETS:
        obj = bpy.data.objects.get(target)
        action = clip_action(clip, target)
        if obj is None:
            missing.append(f"object:{target}")
            continue
        if action is None:
            missing.append(f"action:{clip}__{target}")
            continue
        adt = obj.animation_data_create()
        adt.action = action
        slot = action.slots.get(f"OB{target}")
        if slot is None and adt.action_suitable_slots:
            slot = adt.action_suitable_slots[0]
        if slot is not None:
            adt.action_slot = slot
        assigned += 1
    return assigned, missing


def _autocomplete_clip(clip, context):
    """Ensure `clip` defines all 5 target Actions before it is applied.

    A clip that omits a target (e.g. legacy `base_anim`, which only has
    body_ctrl + foot_target_fl) is NOT switch-safe: Apply leaves that
    target bound to whatever the *previous* clip put there, so you get a
    mixed pose. Here we create the missing `<clip>__<target>` Actions and
    key them once at the NEUTRAL pose, so the target holds neutral across
    the clip instead of inheriting the previous clip. This permanently
    repairs the clip the first time it is applied.

    Neutral = the N-pose foot positions (via _n_pose_foot_targets) for
    foot targets; identity/home for body_ctrl. Returns the list of
    targets that were auto-created."""
    fixable = [
        t
        for t in CLIP_TARGETS
        if bpy.data.objects.get(t) is not None and clip_action(clip, t) is None
    ]
    if not fixable:
        return []

    # N-pose foot positions (only needed/cost if a foot target is missing)
    npos = None
    if any(t.startswith("foot_target_") for t in fixable):
        try:
            arm = _find_arm_obj()
            if arm is not None:
                npos = _pose_foot_targets(arm, _load_convention()["neutral_joint_deg"])
        except (ValueError, KeyError) as e:
            print(
                f"[fh_clip_panel] auto-complete: no N pose ({e}); "
                "keying missing targets at their current transform"
            )

    body_act = clip_action(clip, "body_ctrl")
    frame = int(body_act.frame_range[0]) if body_act else context.scene.frame_start

    repaired = []
    for target in fixable:
        obj = bpy.data.objects[target]
        action = _keep_action(bpy.data.actions.new(f"{clip}__{target}"))
        action.slots.new(id_type="OBJECT", name=target)
        adt = obj.animation_data_create()
        adt.action = action
        slot = action.slots.get(f"OB{target}")
        if slot is None and adt.action_suitable_slots:
            slot = adt.action_suitable_slots[0]
        if slot is not None:
            adt.action_slot = slot

        if target == "body_ctrl":
            obj.location = (0.0, 0.0, 0.0)
            obj.rotation_euler = (0.0, 0.0, 0.0)
            obj.keyframe_insert("location", frame=frame)
            obj.keyframe_insert("rotation_euler", frame=frame)
        else:
            leg = target.removeprefix("foot_target_")
            if npos is not None and leg in npos:
                mw = obj.matrix_world.copy()
                mw.translation = npos[leg]
                obj.matrix_world = mw
            obj.keyframe_insert("location", frame=frame)
        repaired.append(target)

    context.view_layer.update()
    return repaired


def _redraw_view3d(context):
    """Force panels to redraw so they reflect data changes immediately.

    Tags every area in every open window — not just one VIEW_3D via
    `context.screen` — because the Clips panel's per-row include/exclude
    checkbox is an operator button whose icon is computed in draw(); without a
    redraw of the N-panel's region it keeps a stale visual (the toggle data
    updates, the tick doesn't move) until the next mouse event."""
    wm = getattr(bpy.context, "window_manager", None)
    if wm is None:
        if context.screen is not None:
            for area in context.screen.areas:
                area.tag_redraw()
        return
    for window in wm.windows:
        for area in window.screen.areas:
            area.tag_redraw()


# ---------------------------------------------------------------------------
# Export-selection state
# ---------------------------------------------------------------------------
#
# The set of clips ticked for "Export Selected Clips" is stored as a
# newline-joined string on the scene (`fh_export_selected_clips`).
# Clip names can contain spaces ("Lie flat and stand up") but never
# newlines, so '\n' is the safe delimiter. Reads always intersect with
# the live clip set so stale entries (clip deleted/renamed elsewhere)
# auto-prune; writes always sort for stable diffs.


def _export_selected_set():
    """Return the set of clip names currently ticked for selective export,
    intersected with `list_clips()` so stale entries auto-prune."""
    raw = bpy.context.scene.fh_export_selected_clips
    if not raw:
        return set()
    return {n for n in raw.split("\n") if n} & set(list_clips())
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

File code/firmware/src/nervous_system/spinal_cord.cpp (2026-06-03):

#include <Arduino.h>
#include <Wire.h>
#include <math.h>
#include <Adafruit_PWMServoDriver.h>
#include "leg.h"
#include "spinal_cord.h"
#include "servo.h"
#include "motion_math.h"
#include "movements.h"
#include "neutral_pose.h"   // NEUTRAL[] — single source of truth (FL=135 post-Change-B)
#include "../shared/config.h"
#include "clips_all.h"   // generated FH_CLIPS[] (placeholder until export, see B6)

static const uint32_t CLIP_RETURN_MS = 500;  // ease to NEUTRAL at clip end

// Per-channel EMA smoothing applied to clip-playback angles ONLY (inside tickClip).
// smoothed = alpha*prev + (1-alpha)*target. Higher = smoother but laggier. The
// live value lives in clipEmaAlpha_ (runtime-tunable via T:11; boot default in
// spinal_cord.h). Clamped to [0, MAX] on set so playback can never fully stall.
static const float CLIP_EMA_ALPHA_MAX = 0.95f;

// T:6 (CMD_ACTION_SELECTION invert) is a stateless toggle; a duplicated/retried
// packet would double-flip. Ignore a second invert within this window. The app
// (PR #99) is the primary guard against the spam; this is firmware-side insurance.
static const uint32_t INVERT_DEBOUNCE_MS = 250;

// Glide time when an invert toggle mirrors the current pose in place.
static const uint32_t INVERT_EASE_MS = 300;

// Glide time when a gait stops gracefully and settles to the standing pose.
static const uint32_t GAIT_STOP_EASE_MS = 300;

// Glide time when a clip starts: ease from the live pose into the clip's first
// frame before real playback begins, so a clip never snaps from the current pose.
static const uint32_t CLIP_PREROLL_MS = 200;

// Gait parameters (step values are in degrees, pre-scaled to 2/3 of raw JS values).
// Offsets order: [LEG_FR, LEG_FL, LEG_RR, LEG_RL]
// Declaration in movements.h; definition here so the table stays next to the gait engine.
const GaitParams GAITS[] = {
    { 0.0f, 0.0f,  0.0f,  0.0f,  { 0.0f,  0.0f,  0.0f,  0.0f  }, "None"        },
    { 2.0f, 26.7f, 26.7f, 0.75f, { 0.5f,  0.0f,  0.25f, 0.75f }, "Static Walk" },
    { 1.5f, 26.7f, 33.3f, 0.50f, { 0.5f,  0.0f,  0.0f,  0.5f  }, "Trot"        },
    { 1.5f, 20.0f, 33.3f, 0.50f, { 0.5f,  0.0f,  0.0f,  0.5f  }, "Crab"        },
};

SpinalCord::SpinalCord(uint8_t pwm):
    robotState(STATE_IDLE),
    driver(Adafruit_PWMServoDriver(ADDR_SERVO_DRIVER)),
    face(),
    legs_{
        Leg(driver, 0,  // FR
            Servo(driver, FRONT_RIGHT_LEG_HIP_PCA_CHANNEL,    FRONT_RIGHT_LEG_HIP_DEFAULT_ANGLE),
            Servo(driver, FRONT_RIGHT_LEG_THIGH_PCA_CHANNEL,  FRONT_RIGHT_LEG_THIGH_DEFAULT_ANGLE),
            Servo(driver, FRONT_RIGHT_LEG_KNEE_PCA_CHANNEL,   FRONT_RIGHT_LEG_KNEE_DEFAULT_ANGLE)),
        Leg(driver, 1,  // FL
            Servo(driver, FRONT_LEFT_LEG_HIP_PCA_CHANNEL,     FRONT_LEFT_LEG_HIP_DEFAULT_ANGLE),
            Servo(driver, FRONT_LEFT_LEG_THIGH_PCA_CHANNEL,   FRONT_LEFT_LEG_THIGH_DEFAULT_ANGLE),
            Servo(driver, FRONT_LEFT_LEG_KNEE_PCA_CHANNEL,    FRONT_LEFT_LEG_KNEE_DEFAULT_ANGLE)),
        Leg(driver, 2,  // BR/RR
            Servo(driver, BOTTOM_RIGHT_LEG_HIP_PCA_CHANNEL,   BOTTOM_RIGHT_LEG_HIP_DEFAULT_ANGLE),
            Servo(driver, BOTTOM_RIGHT_LEG_THIGH_PCA_CHANNEL, BOTTOM_RIGHT_LEG_THIGH_DEFAULT_ANGLE),
            Servo(driver, BOTTOM_RIGHT_LEG_KNEE_PCA_CHANNEL,  BOTTOM_RIGHT_LEG_KNEE_DEFAULT_ANGLE)),
        Leg(driver, 3,  // BL/RL
            Servo(driver, BOTTOM_LEFT_LEG_HIP_PCA_CHANNEL,    BOTTOM_LEFT_LEG_HIP_DEFAULT_ANGLE),
            Servo(driver, BOTTOM_LEFT_LEG_THIGH_PCA_CHANNEL,  BOTTOM_LEFT_LEG_THIGH_DEFAULT_ANGLE),
            Servo(driver, BOTTOM_LEFT_LEG_KNEE_PCA_CHANNEL,   BOTTOM_LEFT_LEG_KNEE_DEFAULT_ANGLE)),
    },
    currentGait_(GAIT_NONE),
    gaitPhaseStartMs_(0),
    targetX(0.0f), targetY(0.0f), targetYaw(0.0f),
    activeX(0.0f), activeY(0.0f), activeYaw(0.0f),
    isMovingRequested(false), lastCommandMs(0), isInverted(false)
    , clipState_{ CLIP_DONE, 0, 0, 0, 0 }
    , lastInvertMs_(0), hasInverted_(false)
{
    for (uint8_t i = 0; i < LEG_COUNT; ++i)
        for (uint8_t j = 0; j < 3; ++j)
            lastStreamAngles_[i][j] = 999.0f;  // sentinel: first T:12 frame always writes through
}

void SpinalCord::begin() {
    driver.begin();
    driver.setPWMFreq(60);
    isInverted = false;
    hasInverted_  = false;   // clear invert-debounce state on boot
    lastInvertMs_ = 0;
    for (uint8_t i = 0; i < LEG_COUNT; ++i) legs_[i].returnToDefaultAngles();

    face.begin();
    face.setState(EYES_FRONT);
}
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

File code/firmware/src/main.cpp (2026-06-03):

#include <Arduino.h>
#include "brain/network.h"
#include "brain/diagnostics.h"
#include "brain/sensors.h"
#include "shared/data.h"
#include "nervous_system/spinal_cord.h"

SpinalCord spinalCord(0);

void setup() {
    Serial.begin(115200);
    delay(2000);
    spinalCord.begin();
    initNetwork();
    // Boot-time orientation: initSensors() reads ONE accel sample and uses a
    // hardcoded UPRIGHT reference to decide whether to start in upright or
    // inverted mode. Returns a result struct; main.cpp acts on it to keep the
    // brain layer decoupled from nervous_system/spinal_cord.h.
    {
        SensorBootResult boot = initSensors();
        if (boot.inverted) spinalCord.setInverted(true);
    }
    diagnostics::begin(spinalCord);

    Serial.println("FaceHugger OS Online.");
}

void loop() {
    updateNetwork();
    tickImu();

    // Auto-flip gate. The edge-trigger latch lives on SpinalCord so the SIL
    // (bindings.cpp::tick) gets identical behavior without duplicating the
    // logic. The 150°/30° IMU hysteresis already prevents chatter near 90°.
    spinalCord.tickAutoInvert(imuIsInverted());

    spinalCord.update();
    diagnostics::tick();
    diagnostics::handleHttp();

    // Heartbeat every 5 seconds
    static unsigned long lastHeartbeat = 0;
    if (millis() - lastHeartbeat > 5000) {
        lastHeartbeat = millis();
        Serial.println("Robot Pulse: OK");
    }
}

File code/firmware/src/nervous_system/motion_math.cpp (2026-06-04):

#include "motion_math.h"
#include <math.h>
#include "../shared/config.h"  // CALIB_*, SHOULDER_THETA_*, INTER_LEG_BUFFER_DEG
#include "neutral_pose.h"      // NEUTRAL[] math-space rest
#include "clips_all.h"

// Per-side asymmetric URDF-θ envelope. LEFT/RIGHT mirror each other through
// the body-X axis: the URDF tight (narrow) bound is on the same physical
// "inward" side for both, but its signed value flips with side.
//   LEFT  (FL, BL):  θ ∈ [-NARROW, +WIDE]   (URDF + sweeps outward)
//   RIGHT (FR, BR):  θ ∈ [-WIDE,   +NARROW] (mirror)
static inline void shoulder_hard_clamp_for_side(double& theta, bool is_left) {
    const double lo = is_left ? -(double)SHOULDER_THETA_NARROW_DEG
                              : -(double)SHOULDER_THETA_WIDE_DEG;
    const double hi = is_left ? +(double)SHOULDER_THETA_WIDE_DEG
                              : +(double)SHOULDER_THETA_NARROW_DEG;
    if (theta < lo) theta = lo;
    if (theta > hi) theta = hi;
}

// Signed CCW arc from a to b, normalised into (-180, +180]. Positive means b
// is CCW of a; magnitude is the shorter-arc distance.
static inline double signed_shorter_arc(double a, double b) {
    double d = fmod(b - a, 360.0);
    if (d <= -180.0) d += 360.0;
    if (d >   180.0) d -= 360.0;
    return d;
}

// Push `back` away from `front` along the shorter-arc direction so the gap is
// exactly INTER_LEG_BUFFER_DEG. Direction = sign of the current signed arc
// (preserves which side back currently sits on). Returns the adjusted back
// math angle, NOT yet hard-clamped.
static inline double widen_gap_to_buffer(double front_math, double back_math) {
    const double buf = (double)INTER_LEG_BUFFER_DEG;
    double signed_d = signed_shorter_arc(front_math, back_math);
    double sign = (signed_d >= 0.0) ? 1.0 : -1.0;
    return front_math + sign * buf;
}

void enforceShoulderLimits(double sh[4]) {
    // 1. Hard clamp each leg to its per-side URDF-θ envelope.
    double theta[4];
    for (int i = 0; i < 4; ++i) theta[i] = sh[i] - (double)NEUTRAL[i].sh;
    shoulder_hard_clamp_for_side(theta[0], /*is_left=*/false);  // FR
    shoulder_hard_clamp_for_side(theta[1], /*is_left=*/true);   // FL
    shoulder_hard_clamp_for_side(theta[2], /*is_left=*/false);  // BR (RR)
    shoulder_hard_clamp_for_side(theta[3], /*is_left=*/true);   // BL (RL)
    double m[4];
    for (int i = 0; i < 4; ++i) m[i] = (double)NEUTRAL[i].sh + theta[i];

    // 2. Same-side gap: front leads, back follows. If the math-space shorter-
    //    arc gap is below the buffer, push the back leg along the gap-widening
    //    direction. Re-apply the back leg's hard clamp in case the push
    //    crossed its envelope.
    const double buf = (double)INTER_LEG_BUFFER_DEG;

    // RIGHT: FR=0, BR=2
    if (fabs(signed_shorter_arc(m[0], m[2])) < buf) {
        double pushed = widen_gap_to_buffer(m[0], m[2]);
        double pushed_theta = pushed - (double)NEUTRAL[2].sh;
        shoulder_hard_clamp_for_side(pushed_theta, /*is_left=*/false);
        m[2] = (double)NEUTRAL[2].sh + pushed_theta;
    }
    // LEFT: FL=1, BL=3
    if (fabs(signed_shorter_arc(m[1], m[3])) < buf) {
        double pushed = widen_gap_to_buffer(m[1], m[3]);
        double pushed_theta = pushed - (double)NEUTRAL[3].sh;
        shoulder_hard_clamp_for_side(pushed_theta, /*is_left=*/true);
        m[3] = (double)NEUTRAL[3].sh + pushed_theta;
    }

    for (int i = 0; i < 4; ++i) sh[i] = m[i];
}

uint32_t clampPoseEaseMs(uint32_t dur_ms) {
    // 0 ("snap") is preserved; otherwise cap at POSE_EASE_MS_MAX. uint32_t so a
    // wire negative read as int becomes a huge unsigned and clamps to MAX, not 0.
    return dur_ms > (uint32_t)POSE_EASE_MS_MAX ? (uint32_t)POSE_EASE_MS_MAX : dur_ms;
}

double easeFraction(uint32_t elapsed_ms, uint32_t dur_ms) {
    if (dur_ms == 0 || elapsed_ms >= dur_ms) return 1.0;
    double t = (double)elapsed_ms / (double)dur_ms;
    return t * t * (3.0 - 2.0 * t);  // smoothstep
}
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

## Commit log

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2026-04-02 feat: implement WebSocket server and JSON command parsing logic
    - Initialized WiFi Access Point (FaceHugger_Net)
    - Implemented WebSocket event loop with corrected WStype_t signatures
    - Integrated ArduinoJson 7 parser to handle CMD_MOVE, CMD_STATE, and CMD_CALIBRATE
    - Verified command routing via Serial Monitor logging
    - Fixed type-mismatch errors in network.h/cpp
    [main.cpp, network.cpp]
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2026-04-17 feat(spinal-cord): implement modular leg abstraction and v1.1 API
    - Refactor Leg class to handle hardware-specific mapping and constraints.
    - Implement SpinalCord manager to coordinate 4-leg movement via a state machine.
    - Update WebSocket handler to support API Spec v1.1 (x, y, z, r, g vectors).
    - Replace raw PWM calibration with angle-based T:4 commands for safer hardware bring-up.
    - Decouple Network logic from Physical logic using extern singleton pattern.
    - Add safety clamping (0-180/270°) to prevent mechanical servo stall.
    [config.h, leg.cpp, main.cpp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]
2026-04-19 refactor(spinal-cord): stabilize I2C traffic and calibrate PWM ranges
    - Defer PCA9685 initialization to spinalCord.begin().
    - Correct PCA9685 mapping by updating MIN_PULSE (150) and MAX_PULSE (600) to 12-bit standard.
    - Remove redundant servo update calls in STATE_IDLE to prevent I2C bus flooding.
    [config.h, leg.cpp, main.cpp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]
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2026-04-23 feat(simulation): add Fusion→URDF pipeline with real geometry and inertia
    - ExportBodiesToURDF.py: recursive Fusion assembly traversal, outputs
    fusion_export.json + STLs to code/simulation/ via repo-relative path;
    collects physical properties (mass, CoM, inertia) from Fusion API
    - facehugger_config.yaml: robot hierarchy config mapping Fusion construction
    geometry to URDF links/joints; 4-leg instantiation from one template
    - generate_urdf.py: reads export JSON + config, generates facehugger.urdf
    with precise joint origins, axes, and inertial data from Fusion
    - facehugger.urdf: regenerated with real coordinates from Fusion geometry,
    correct DS3230MG effort (2.94 Nm), 4 independent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
    [QuadrupedBody.stl, facehugger.urdf, leg_lower.stl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]
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2026-04-24 feat(simulation): per-instance servo rpy from CAD occurrence rotations
    Every servo <visual> in the URDF used to emit rpy="0 0 0". That's only
    correct for the CAD's single source leg instance (FL) — the 4-way
    shoulder fan-out on base_link and hip/knee servos on the 3 virtual
    sibling legs all inherited a default LAL orientation regardless of which
    corner they sit at.
    Fix: derive each servo visual's rpy from fusion_export.json's
    world_transform_rm_cm. Added helpers:
    _servo_rot_by_role # 3x3 rotation of a servo by shoulder/hip/knee
    _find_occ_rot # find any occurrence's world rotation by leaf name
    _mat_mul_3x3, _mat_transpose_3x3
    _rot_to_urdf_rpy # ZYX decompo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
    [facehugger.urdf]
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2026-04-24 feat(simulation): `servo.visual_flip_rpy_deg` for uniform mesh flip
    Adds a yaml knob to rotate every servo <visual> in the mesh's own local
    frame, layered on top of the per-instance rpy already derived from the
    CAD's occurrence rotations. Default is a 180° X flip because the
    current Fusion model exports servos pointing opposite to how they sit
    on the physical robot; the flip aligns the rendered servos with the
    CAD body without requiring a Fusion re-orientation pass.
    - Adds `servo.visual_flip_rpy_deg: [180, 0, 0]` under the existing
    `servo:` block. Set to [0, 0, 0] to trust the CAD verbatim.
    generate_urdf.py:
    - Adds `_euler_to_rot(rpy_rad)` (URDF convention R = Rz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
    [facehugger.urdf]
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2026-04-24 feat(sim): treat shoulder servos as chassis-fixed, uniform orientation
    The shoulder servo is physically bolted to the chassis bracket (not the
    rotating leg), so give all four visuals the source-leg (FL) orientation
    and only translate to the four LegMountXX corners. This removes the
    "2 servos below, 2 above" artifact that the CAD's per-bracket rotations
    (Rx/Ry/Rz(180°)) were propagating: LegMountFR=Rx(180°) and
    LegMountBL=Ry(180°) flipped Z on those two corners, so FR/BL shoulder
    servos ended up 46mm below their mount while FL/BR were 46mm above.
    Blender: shoulder servos now live in a new FusionExport/Shoulders
    sub-collection (not under Legs/{corner}), so rotating a leg's root
    Empty no lo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
    [facehugger.urdf]
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2026-04-29 feat(locomotion): implement 4-phase gait trajectory and vector mapping
    Upgraded the SpinalCord execution loop from a 2-phase stub to a fully dynamic 4-phase locomotion engine (Lift, Move, Lower, Stance).
    Key additions:
    - Added processCommand to map discrete remote strings (e.g., 'FW_R') to normalized 2D target vectors.
    - Implemented input smoothing (Lerp) on active vectors to prevent mechanical jerking.
    - Added a 500ms Deadman's Switch timeout for network safety.
    - Implemented 'Graceful Stop' logic to ensure the robot finishes its current stride before returning to IDLE.
    - Created applyIMUCorrection hook for future MPU6050 integration.
    [spinal_cord.cpp]
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2026-04-30 feat(sim): leg-assembly normalization + standalone servos align URDF
    Fixes two compounding bugs that put the legs in the wrong place in
    PyBullet: (1) shoulder joint origin was at the mounting tab instead
    of the rotation axis (38mm off), and (2) FaceHuggerLegAssembly's
    90°-about-Z world rotation wasn't compensated for, leaving meshes
    and joint axes 90° off.
    Exporter (Phase E)
    - Compute R_la = leg-assembly's 3x3 world rotation; pass into
    collect_joints() and apply to axis_dir / axis_origin for joints
    owned by FaceHuggerLegAssembly. JSON now carries world-aligned
    joint data.
    - Convert all leg-assembly-internal body-rule entries to combined-rule
    (single-part). Combined-rule already ba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
    [facehugger.urdf, leg_lower.stl, leg_mount_L.stl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]
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2026-04-30 refactor(sim): drop v1 simulator and URDF
    The v1 hand-written single-file simulator and facehugger_v1.urdf are
    preserved in this branch's git history for personal reference but no
    longer needed in the working tree. Rip the v1 code paths out of
    simulate_v2.py:
    - Drop URDF_V1, STANCE_DEG_V1, _V1_LEG_INFO/_V1_JOINT_LIMITS/_V1_L*
    - Remove fk_v1, ik_v1, build_config_v1
    - Remove cfg.version field and the v2-vs-v1 branching everywhere
    - Drop the --urdf argparse option (build_config replaces build_config_v2)
    - Collapse "offsets_v2" -> "offsets" in the gait registry
    - Update README so the listed flags reflect the v2-only surface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
    [facehugger_v1.urdf]
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2026-04-30 refactor(sim): collect generated artifacts under generated/
    Move fusion_export.json/.txt, exported_meshes/, and facehugger.urdf
    into code/simulation/generated/ so the simulation root only carries
    hand-edited files (config + scripts + docs).
    Update hardcoded paths in:
    - simulate_v2.py, view_urdf.py, generate_urdf.py (URDF/JSON/mesh paths)
    - ExportBodiesToURDF.py (Fusion add-in writes to generated/)
    - visualize_fusion_export.py (default --export and --meshes paths)
    - README + docs (file map and example commands)
    The yaml's mesh_dir stays "exported_meshes/" because it's relative to
    the URDF location, which is now generated/facehugger.urdf — the same
    relative subpath still resolves correctly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
    [QuadrupedBody.stl, facehugger.urdf, leg_lower.stl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]
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2026-05-03 chore(sim): regenerate URDF + STLs + fusion_export with rest-value fix
    Re-run of the Fusion exporter (post-fix from b70b771) followed by
    \`python facehugger.py urdf\`. The diff is mostly binary (STLs +
    JSON), but the semantic change worth eyeballing is in
    fusion_export.json:
    Link1Revolute.limits_rad.rest: 0.0 -> -0.7853981633974483 rad
    (= -45 deg)
    Link2Revolute.limits_rad.rest: 0.0 -> 0.0 (no change; rest = 0)
    Link3Revolute.limits_rad.rest: 0.0 -> 0.0 (no change; rest = 0)
    The URDF itself does NOT yet consume these new rest values — that's
    the Convention A implementation still to land in generate_urdf.py
    (tracked in MER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
    [facehugger.urdf, leg_shoulder_L.stl, leg_shoulder_R.stl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]
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2026-05-03 fix(urdf): swap BL/BR signs in Convention A shoulder rest formula
    The previous _shoulder_rest_for() had BL and BR swapped (signs flipped
    relative to what makes back legs splay outward). With FL = -π/4 from
    the current CAD, the wrong formula gave BL=+135° / BR=-135°, which
    sent the back legs pointing into the FRONT quadrants — visible in
    Blender as BL aiming toward the FL corner and BR toward FR.
    Correct mapping (verified against Blender visualizer):
    FL = fl_rest_rad (= -45° from current CAD)
    FR = -fl_rest_rad (= +45°)
    BL = -wrap_pi(FL + π) (= -135°) ← sign flipped from previous
    BR = wrap_pi(FL + π) (= +135°) ← sign flipped from p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
    [facehugger.urdf]
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2026-05-04 feat(kinematics): implement absolute global angles and mirrored hardware logic
    - **Adopted Absolute Angle Convention:** Shoulders now use global polar coordinates (0° = Right, 90° = Forward). Thigh and Knee joints now use an absolute horizontal 0° reference, eliminating relative joint-space dependencies.
    - **Rewrote leg.cpp::setPose():** Transformed into a pure hardware translator. It now takes pure geometric IK angles and converts them to 0-180° physical servo pulses.
    - **Implemented Hardware Mirroring:** Added robust 90 +/- translation logic inside setPose() to automatically handle the physically inverted left-side servos without requiring changes to the IK engine.
    - **Added Safety Cla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
    [config.h, leg.cpp, network.cpp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]
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2026-05-05 refactor(kinematics) : change leg kinematics for diagonal symmetry and update docs (v2.0)
    - Overhauled leg.cpp to use an Absolute Geometric Coordinate System
    (0° = horizontal) instead of manual offset hunting.
    - Added Diagonal Symmetry logic to correctly map pure math to the
    physically mirrored Left/Right servos.
    - Completely updated
    ervous_system/README.md to reflect the new
    3-layer software architecture (Gait Engine, Math Brain, Hardware Translator).
    [config.h, leg.cpp, network.cpp]
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2026-05-05 fix(urdf): snap near-zero axis components to 0 + renormalize
    Fusion-derived joint axes carry FP dust on the should-be-zero columns
    (e.g. [2.77e-17, -2.99e-17, 1.0000000000000002]), which some URDF
    consumers reject as non-unit or treat as truly off-axis. Add a
    clean_axis helper and call it in URDF.joint so emitted <axis xyz=...>
    elements are exact unit vectors like "0.0 0.0 1.0".
    [facehugger.urdf]
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2026-05-11 feat(urdf): shoulder three-flip on R-side + new-CAD pipeline updates
    CAD redesign brought a smaller chassis (body track 83→68 mm × 98→92 mm),
    raised shoulder pivot (BodyToLink1Point Z −4.2 → +41.8 mm), two new
    structural bodies (MiddleBridge, BehindBridge) under QuadrupedBody:1,
    and asymmetric Fusion shoulder limits ([-97°, +25°] about FL rest).
    Generator changes:
    - Apply the same axis-negation + limit negate-and-swap pattern that
    hip/knee already use on R-side (FR + BL) to the shoulder joint.
    Without this, asymmetric Fusion limits get applied identically to
    every leg, leaving FR/BL with a mirrored sweep window. Convention A
    is preserved — the per-leg <origin rpy> still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
    [QuadrupedBody.stl, facehugger.urdf, leg_lower.stl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]
2026-05-11 feat(cad): print-ready STL exporter with per-body up-axis rotation
    New Fusion script ExportPrintableSTLs that reads cad/print_export.txt
    (one body per line) and writes HIGH-refinement binary STLs into
    cad/body/ or cad/leg/ — sister to ExportBodiesToURDF, which targets
    sim/URDF consumers at Medium refinement.
    Spec format:
    <subfolder> <body_name> [up_axis] [hint]
    up_axis ∈ {+X, -X, +Y, -Y, +Z, -Z} bakes a fixed rotation into the
    STL after Fusion writes it, so each part loads pre-oriented in the
    slicer. hint disambiguates when the same body name appears in
    multiple components (none required for the current design).
    After every run, the section below the marker
    # === EXPORT LO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
    [BehindBridge.stl, LegMountL.stl, LegMountR.stl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]
2026-05-11 fix(cad): rename L-side Link1 body to Link1L for naming symmetry
    The L-side shoulder body lived inside Link1L:1 component but was named
    Link1 — odd against its R-side counterpart Link1R. Renaming it to
    Link1L makes the body name match its component and parallel the R
    variant, simplifying spec lines and the assembly sanity-check dict.
    Touches both export scripts because both reference the body name:
    - ExportBodiesToURDF: leg_shoulder_L.stl combined-rule + the
    _REQUIRED_FHLA_OCCS sanity-check dict.
    - print_export.txt: spec entry "leg Link1 -X" → "leg Link1L -X".
    Leg-side STLs in cad/leg/ regenerated at HIGH refinement (Link1L
    rename + Link1R/Link2/Link3 re-export to keep the set in syn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
    [Link1.stl, Link1L.stl, Link1R.stl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]
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2026-05-16 fix(code): fix boot crash and websocket port mismatch
    Remove hardware I2C calls from Servo and Leg constructors — they ran
    during static initialization before driver.begin(), causing a null
    pointer crash. SpinalCord::begin() already calls returnToDefaultAngles()
    after the driver is up. Also fix app WebSocket port from 8080 to 81 to
    match the firmware server.
    [leg.cpp, main.cpp, network.cpp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]
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2026-05-18 fix(animation): read IK-solved joint angles from evaluated pose matrix
    _read_bone_angles (used by BOTH clip export and the activity heatmap)
    read pose.bones[name].rotation_euler[JOINT_ROT_AXIS[name]]. The IK /
    Damped-Track / Limit-Rotation constraint stack writes the solved pose
    into each pose bone's evaluated `matrix`, never into `rotation_euler`
    or `matrix_basis` — so every IK-driven hip/knee bone read exactly 0.
    Result: hello.csv/.h exported all zeros across all frames and the
    heatmap never lit up.
    Fix: recover the *effective* basis — the matrix_basis the bone would
    hold if its evaluated pose had been keyed directly instead of
    constraint-solved — via Bone.convert_local_to_pose(...,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
    [fh_clip_panel.py]
2026-05-18 feat(animation): servo-mesh activity heatmap + New Clip operator
    Heatmap retargeted from pose bones (armature is hide_viewport=True, so
    bone colours never rendered) to the per-joint `<bone>__servo` meshes via
    object.color, switching View3D solid shading to Object-colour mode while
    active and restoring it losslessly on toggle-off. It reuses
    _read_bone_angles so it inherits the IK-solved-angle fix automatically.
    Known, deliberate gap: link2/hip has no `__servo` mesh (merged into a
    parent body in the CAD→URDF combine step), so only 8 of 12 joints are
    visualised. A one-time console warning, the toggle tooltip and a code
    comment all call this out.
    New Clip operator (FH_OT_new_clip): creates 5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
    [fh_clip_panel.py]
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2026-05-18 refactor(animation): two-layer exporter + CSV/C/JS converters
    Split FH_OT_export_clip into reusable layers:
    LAYER 1 — bake_clip(clip_name, context): pure Blender data extraction
    (scrub frames, evaluate depsgraph, read IK-solved angles via the fixed
    _read_bone_angles). Returns row dicts. No hardware knowledge.
    LAYER 2 — converters writing to animation/exported_gaits/<clip>/:
    • to_csv raw bone angles (legacy format, unchanged)
    • to_c_header static C array of raw angles (unchanged; takes
    `convention` for a uniform signature but stays raw —
    hw conversion is the JS layer's job)
    • to_js self-contained browser-console pla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
    [fh_clip_panel.py]
2026-05-18 refactor(gait): replace metric-space IK loop with angle-space engine mirroring JS simulator
    - Replace setPose(x,y,z) gait loop with setJointAngles() using per-leg NEUTRAL[] table
    matching the physically-tested JS N[] values
    - Port translateToServo() per-leg math from JS to C++ for FR/FL/RR/RL
    - Switch GaitParams from step_length_m/step_height_m to step_length_deg/step_height_deg;
    update all gait presets to 2/3-scaled JS values
    - Add Leg::setJointAngles() with [0,180] clamping
    - Add SpinalCord::relax() and STATE_REST for safe power-off (all joints at 90°)
    - Fix PCA channel assignments: swap bottom-left (0-2) and bottom-right (4-6) channels
    - Update IDLE_STAND default angles to physically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
    [config.h, leg.cpp, spinal_cord.cpp]
2026-05-18 feat(animation): Set N Pose operator (hardware-neutral stance)
    FH_OT_set_n_pose ("Set N Pose" button, below New Clip): reads
    neutral_joint_deg from convention.json, runs a simplified planar FK
    (_n_pose_foot_targets) to compute each leg's foot-tip world position at
    the hardware-neutral pose, and moves foot_target_<leg> there so the
    rig's IK solves to the robot's real starting stance. Click before
    authoring a clip so frame 1 matches hardware.
    FK link lengths (L1/L2/L3) and shoulder-mount world positions are
    fixed rig geometry constants; only N comes from convention.json (never
    hardcoded). foot_y is the sin-component mirror of the spec's foot_x
    (a 3-D foot position needs the in-plane reach on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
    [fh_clip_panel.py]
2026-05-18 fix(animation): Set N Pose — use rig FK, not the broken planar model
    The hand-rolled planar FK in _n_pose_foot_targets was wrong by
    ~340 mm/leg: Z inverted (+177 mm UP) and 3/4 legs in the wrong
    quadrant, so the rig folded up/inward instead of crouching out/down
    (see user screenshots). Root cause: its guessed mount/yaw/sign
    constants did not match the rig's actual kinematics.
    The rig (URDF) is the kinematic source of truth. Per Convention A
    every joint is uniform on bone-local Z, and Part 2's
    scaled = N+(raw-N)*s makes raw == N at the neutral anchor, so the N
    angles in convention.json feed directly into rig joint angles
    (confirmed with the team: +hip = leg up, -hip = leg down; N hip
    -60°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
    [fh_clip_panel.py]
2026-05-18 feat(animation): "Save Current → New Clip" operator
    FH_OT_save_as_clip snapshots whatever actions are CURRENTLY bound to
    the 5 control objects (read live via obj.animation_data.action, not by
    name) into <new_name>__* and switches to the new clip. Unlike
    Duplicate it does not need active_clip() to resolve, so it works even
    when the bound action names have drifted from the convention or you
    just started keyframing on a fresh rig.
    Workflow it enables: start on base_anim → animate → "Save Current →
    New Clip" → name it → your work is a new clip and you're switched to
    it.
    Caveat handled honestly: editing while a clip is active mutates THAT
    clip's actions in place (Blender's layered-A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
    [fh_clip_panel.py]
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2026-05-18 feat(animation): auto-complete incomplete clips on Apply (switch-safe)
    A clip that omits a target (legacy base_anim only has body_ctrl +
    foot_target_fl) was not switch-safe: assign_clip skips missing
    targets, so Apply left them bound to the PREVIOUS clip's action — you
    got a mixed pose (the user's correct intuition: "switching must
    transfer all parts, even ones you didn't keyframe").
    _autocomplete_clip(clip, context), called at the top of
    FH_OT_apply_clip, creates any missing <clip>__<target> Actions and
    keys them once at the NEUTRAL pose so the target holds neutral across
    the clip instead of inheriting the previous clip:
    - foot_target_<leg>: the N-pose foot position from
    _n_pose_fo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
    [fh_clip_panel.py]
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2026-05-18 feat(gait): port validated JS v7.5 trot to firmware
    Replace the generic shoulder-sweep trot with a faithful port of the
    4-phase 'strict square motion' JS reference. Front legs use discrete
    hip_in/hip_out targets with constant lift during swing; rear legs use
    a continuous hip sweep with sinusoidal lift. All joint deltas are
    scaled by 2/3 around neutral to match scalePose(). activeY magnitude
    scales stride; negative activeY reverses the cycle for backward.
    [spinal_cord.cpp]
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2026-05-19 fix(gait): anchor trot front legs at neutral when mag is zero
    During pure-yaw input (diagonals) mag=|activeY|=0, but the previous
    front-leg block collapsed ho to hi, leaving FR commanded to math sh=65
    (servo ~103) instead of its neutral 45 (servo 90). The 13 degree
    forward bias on a single front foot turned in-place rotation into a
    backward arc. Scale the hip-back/hip-front endpoints as deltas from
    neutral so mag=0 holds both fronts exactly at neutral.
    [spinal_cord.cpp]
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2026-05-19 feat(animation): add "Set Flat Pose" (URDF rest) alongside Set N Pose
    Adds a second pose button. The flat/base pose = URDF θ=0 (all joint
    angles 0) — the splayed "Superman" stance the rig builder sets on
    every --rigged rebuild. Use it to snap the rig back to the known
    baseline (e.g. before authoring, or to undo a crouch).
    Refactor (DRY): _n_pose_foot_targets -> generic _pose_foot_targets
    (it already took a per-leg angle dict); the shared operator body
    (arm lookup, move foot targets, residual report) is factored into
    _drive_to_joint_pose. FH_OT_set_n_pose passes convention.json's
    neutral_joint_deg; FH_OT_set_rest_pose passes all-zeros (no
    convention needed). Buttons sit side by side: "Set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
    [fh_clip_panel.py]
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2026-05-19 feat(animation): position-based Pose Library (poses.json)
    Adds a clip-independent pose library backed by a committed
    animation/poses.json (same single-source-of-truth pattern as
    convention.json). A "pose" is a snapshot of the 5 control objects'
    LOCAL transforms: body_ctrl loc+rot, the 4 foot_target_* loc only
    (the IK reads only foot-target position). Local transforms are stored
    so a pose round-trips with keyframes (the upcoming "Key into Clip").
    _poses_path / _load_poses / _save_poses — JSON I/O; missing file is
    not an error, corrupt JSON raises so it can't silently lose data;
    written sorted+indented for clean git diffs.
    _capture_pose / _apply_pose — pure sn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
    [fh_clip_panel.py]
2026-05-19 feat(animation): selection-set buttons for rig controls
    New "Selection" panel section: one operator (fh.select_controls,
    preset arg) with buttons All / Body / Legs / Front / Back / FL / FR /
    BL / BR. Body = body_ctrl; Front/Back = the two front/back foot
    targets; Legs = all 4 feet; All = the 5 controls. Each press REPLACES
    the current selection and makes one member active — pure viewport
    selection, no transforms / keyframes / Actions touched. Missing or
    view-layer-excluded controls are skipped with a warning rather than
    erroring.
    Headless-verified: preset table (9 entries), every preset's selected
    set + active object, preset-switch-replaces-not-accumulates, and a
    no-data-touched assertion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
    [fh_clip_panel.py]
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2026-05-19 feat(animation): sub-panel UI + N/Flat as seeded library poses
    Decision A — split the monolithic FH_PT_clip_panel into a parent
    "FaceHugger" panel (always-visible active-clip + not-keyed status)
    with five collapsible bl_parent_id sub-panels: Poses / Clips /
    Selection / Export / Display (ordered via bl_order; Display
    DEFAULT_CLOSED). Set N Pose / Set Flat Pose live in the Export
    sub-panel per the plan.
    Decision C — Set N Pose / Set Flat Pose are no longer special
    angle-driving buttons. They now seed two built-in library poses
    ('neutral' from convention.json, 'flat' = URDF θ=0) into poses.json on
    first use via the repurposed _pose_foot_targets machinery
    (_seed_pose_from_angles / _seeded_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
    [fh_clip_panel.py]
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
